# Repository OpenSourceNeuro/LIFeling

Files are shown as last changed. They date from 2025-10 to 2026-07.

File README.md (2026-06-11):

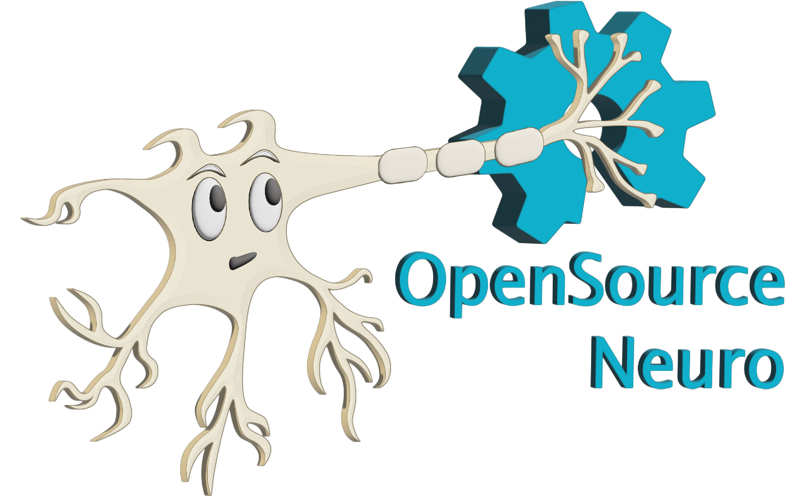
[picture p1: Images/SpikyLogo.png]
<p align="left">

<h1 align="center"> LIFeling </h1></p>
<h3 align="center">  An analog LIF/AdEx “silicon neuron” for teaching & exploration</h3></p>
<p align="center"><h6 align="right">developed by M.J.Y. Zimmermann, A. Koumoundourou</h6></p>

<br></br>

## What is LIFeling
<div>
<p style='text-align: justify;'>
LIFeling is a low-cost, through-hole–friendly analog circuit that emulates a spiking neuron in real time. It implements the Leaky Integrate-and-Fire (LIF) and Adaptive Exponential Integrate-and-Fire (AdEx) dynamics using op-amps, RC networks, comparators, and simple transistor/MOSFET logic.

<p style='text-align: justify;'>
Students can turn knobs (capacitance, leak, synaptic gains, adaptation, threshold, reset) and immediately see how membrane voltage and spikes change—just like a patch-clamp demo, but on an interactive PCB.
</p>

<p style='text-align: justify;'>
LIFeling lives alongside our digital <a href="https://github.com/OpenSourceNeuro/Spikeling">Spikeling</a>: project; where Spikeling runs code, LIFeling is purely analog, making the math–to–hardware mapping very explicit. (For background on AdEx/LIF and neuromorphic “silicon neurons”, <a href="https://www-sop.inria.fr/members/Mathieu.Desroches/teaching/MTSN/Articles/Brette_Gertsner_JNeurophysiol_2005.pdf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">See the references</a>).
</p>

<p style='text-align: justify;'>
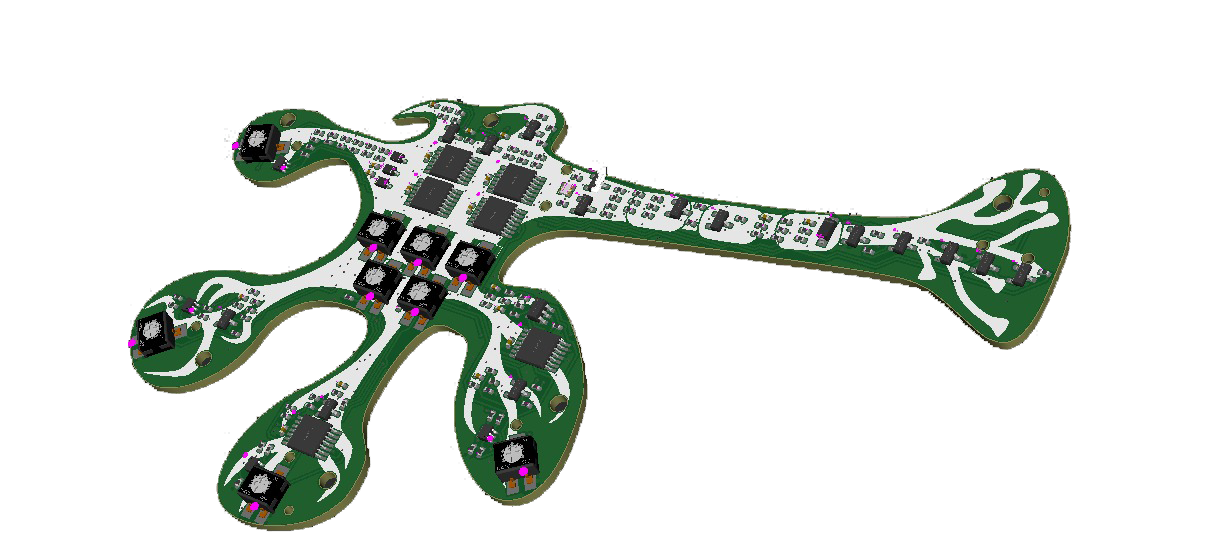
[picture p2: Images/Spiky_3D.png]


This project is licensed under the [GNU General Public License v3.0](https://github.com/OpenSourceNeuro/Spikeling-V2/blob/main/LICENSE)<br>
The hardware is licensed under the [CERN OHL v1.2](https://github.com/OpenSourceNeuro/Spikeling-V2/blob/main/PCB%20-%202.2c/LICENSE)
</p>
</div>

<br>

***

## Objectives
- **Pedagogy** first: Make classical neuron equations tangible with knobs, LEDs, and BNC/TTL I/O so learners can fit parameters from data and build intuition.

- **Open, repairable, reproducible**: THT-preferred BOM where possible; common op-amps (e.g., MCP6004), LM339-class comparators, simple passives; documented test procedures.

- **Immediate feedback**: Real-time dynamics without sampling/latency; scope-friendly nodes for Vm, synaptic currents, threshold comparator, adaptation current.

- **Bridging models**: Start with LIF; switch in AdEx features (exp spike term + adaptation) to show how richer behaviours emerge with just a few components.

- **Teaching exercises**: Provide ready-to-run lab activities (τm measurement, I–F curves, refractory period, synaptic summation, adaptation fitting, noise & reliability). (See Exercises below.)

- **Interoperability**: Optional headers/IO for stimulus/recording from microcontrollers (ESP32/Arduino) and classroom oscilloscopes.

## The models LIFeling implements

#### 1) Leaky Integrate-and-Fire (LIF)

```math
C_m * dV/dt = -g_L * (V - E_L) + I_syn(t) + I_inj(t) - w(t)
```

If V >= V_th  ⇒  V ← V_reset  and hold for τ_ref

with synaptic drive typically modeled as:

```math
I_syn(t) = Σ_i g_i(t) * (E_i - V)
```

LIF captures integration, leakage, threshold, reset, and refractory with minimal parameters.

### Adaptive Exponential Integrate-and-Fire (AdEx)

```math
C_m * dV/dt = -g_L * (V - E_L)
              + g_L * Δ_T * exp((V - V_T)/Δ_T)
              - w
              + I_syn(t) + I_inj(t)

τ_w * dw/dt = a * (V - E_L) - w

If V >= V_spike  ⇒  V ← V_reset  and  w ← w + b
```

AdEx adds a soft, exponential spike-initiation term and an adaptation state w, reproducing rich firing patterns with few parameters.

- Further reading: Brette & Gerstner 2005 (AdEx); Dayan & Abbott 2001 (LIF fundamentals); Indiveri et al. 2011 (neuromorphic neuron circuits).

## Circuit ↔ equation map

| Equation term | Biological meaning | Circuit element(s) | What to adjust / observe |
|---|---|---|---|
| `C_m` | Membrane capacitance (area/biophysics) | Selectable capacitor bank; front-panel selector | Larger `C_m` → slower `V_m` dynamics; measure a step response to estimate `τ_m = C_m / g_L`. |
| `g_L`, `E_L` | Leak conductance & resting potential | Potentiometer or resistor ladder to ground/bias; optional reference sets `E_L` | Increasing `g_L` lowers input resistance and shortens `τ_m`; trimming `E_L` shifts the baseline. |
| `I_syn = Σ g_i(t) · (E_i − V)` | Synaptic drive (EPSC/IPSC) with reversal | 4× synapse shapers (RC) with gain/polarity pots; bias selects excitatory vs inhibitory | Temporal summation, shunting inhibition; switch time constants (fast/slow) to compare PSP shapes. |
| `Δ_T`, `V_T` | Spike-onset sharpness & soft threshold (AdEx) | Exponential I–V subcircuit (diode/transconductance shaping) feeding the membrane node | Increase `Δ_T` for smoother onset; adjust `V_T` to shift effective threshold and excitability. |
| `w`, `a`, `b`, `τ_w` | Adaptation current and kinetics | Slow RC + transconductance; spike-triggered charge increment into `w` | Fit `a`, `b`, `τ_w` from step protocols; observe spike-frequency adaptation and after-spike effects. |
| Spike detect & reset | Action potential event and absolute refractory | LM339-class comparator → MOSFET/analog switch clamp to `V_reset`; monostable sets `τ_ref` | Tune `V_th`, `V_reset`, `τ_ref`; verify with ISI histograms and two-pulse tests. |
| `I_inj` | Current clamp / external stimulus | BNC/3.5 mm input, on-board button, or photodiode path | Use steps/ramps/noise to probe `f–I` curves, threshold, reliability, and dynamic range. |

## Biological correspondence: what’s faithful vs abstracted

Faithful: passive membrane (R–C), synaptic time courses (first-order), EPSP/IPSP summation, threshold/reset phenomenology, refractory period, spike-frequency adaptation.

Abstracted: no detailed action-potential waveform (we model its effect via threshold/reset); ion-channel kinetics are lumped into **g_L**, the exponential term, and **w** rather than Hodgkin–Huxley-style gates.

Optional background: when teaching resting potentials and synaptic reversal, connect channel-specific reversal potentials **E_i** to Nernst/GHK equations (see References).

## Front-panel controls (typical)

**Membrane**: C_m selector, Leak pot (g_L), E_L trim.

**Synapses (×4)**: Gain pot, Polarity switch (E/I), τ_s switch (fast/slow).

**AdEx**: V_T, Δ_T trims (soft threshold), Adaptation (a, b, τ_w) pots.

**Spiking**: V_th, V_reset, τ_ref trims; Spike LED.

**I/O**: Vm out (scope), Spike out (TTL), Stim in (BNC/3.5 mm), light-sensor jack.

Start with τ_m ≈ 5–100 ms and spike thresholds ~0.8–1.8 V relative to your virtual ground (adjust for your supply).

## Quick start (bench)

Power & baseline. Power the board; set all gains mid-range; choose C_m, set leak mid.

Wire the scope. CH1 = Vm; CH2 = Spike TTL.

Elicit spikes. Inject a 0.5–2 s current step; adjust threshold/reset until regular spiking appears.

Add small Δ_T and adaptation (τ_w ≈ 200–500 ms). Watch firing adapt down.

Play with synapses. Use fast EPSPs and slower IPSPs to demonstrate temporal summation and shunting inhibition.

## Suggested classroom exercises

**Measure membrane time constant τ_m.**
Inject a small subthreshold step; fit V(t) = E_L + ΔV*(1 - exp(-t/τ_m)). Recover C_m or g_L and compare to knob settings.

**I–F (f–I) curve & rheobase.**
Ramp I_inj and record firing rate. Fit slope and rheobase; show how g_L and C_m change slope/offset.

**Refractory period.**
Deliver two pulses separated by Δt; find minimum Δt producing two spikes; compare to τ_ref.

**Synaptic summation and shunting.**
Pair an EPSP with a near-coincident IPSP; demonstrate divisive gain control by increasing inhibitory conductance (shunting).

**Spike-frequency adaptation (AdEx).**
Step-current protocol; fit a, b, τ_w from the early/late rates and the post-spike adaptation jump.

**Soft vs hard threshold.**
Compare LIF (hard V_th) to AdEx (Δ_T > 0). Show smoother onset and different ISI variability with AdEx.

**Noise & reliability.**
Add small noise to I_inj; plot spike-time jitter vs g_L. Discuss reliability/variability trade-offs.

**Analog vs digital (optional).**
Recreate one exercise on a microcontroller neuron (e.g., Izhikevich) and compare dynamics, latency, and parameter identifiability.

## Acknowledgments

Foundation: This project is based on Lu.i — https://github.com/giant-axon/lu.i-neuron-pcb

Thanks to the neuromorphic-hardware community for decades of open designs and teaching inspiration.

## References & further reading

AdEx model — Brette, R. & Gerstner, W. (2005). Adaptive Exponential Integrate-and-Fire Model as an Effective Description of Neuronal Activity. Journal of Neurophysiology, 94(5), 3637–3642. https://doi.org/10.1152/jn.00686.2005

LIF & synapses — Dayan, P. & Abbott, L. F. (2001). Theoretical Neuroscience. MIT Press. (See chapters on LIF, synapses, and I–F curves.)

Neuromorphic circuits — Indiveri, G., Linares-Barranco, B., et al. (2011). Neuromorphic Silicon Neuron Circuits. Frontiers in Neuroscience, 5:73. https://doi.org/10.3389/fnins.2011.00073
 (Open access)

Spiking for teaching (digital reference) — Baden, T., James, B., et al. (2018). Spikeling: a low-cost hardware implementation of a spiking neuron for neuroscience teaching and outreach. PLOS Biology. https://doi.org/10.1371/journal.pbio.2006760

Ion channels & reversals (background) — Hille, B. (2001). Ion Channels of Excitable Membranes (3rd ed.). Sinauer. (Nernst/GHK chapters)

## Contributing

Issues and PRs welcome!
When reporting results, please include:

Scope captures (Vm & Spike TTL),

Knob settings (Cm, gL, ΔT, Vth, Vreset, τref, a, b, τw),

The stimulus used (step amplitude, duration, ramp slope, synaptic timing),

Supply voltage and any modifications to the reference design.

## FAQ

Is this a “real” action potential?
No—the analog spike is implicit (threshold/reset). That’s by design and matches reduced-model pedagogy.

Why analog instead of a microcontroller?
Zero-latency dynamics and a literal circuit-to-equation mapping you can probe with a scope—excellent for intuition building.

Can I add more biology?
Yes: add synapse types (different τ_s), noise sources, or a second compartment. Use the AdEx literature and neuromorphic reviews as guidance.

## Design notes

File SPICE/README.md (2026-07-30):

# LIFeling physical-netlist SPICE validation system

This reconstruction replaces the earlier block-level behavioural generator with a physical-pin-driven workflow for the attached KiCad export dated **2026-07-29 20:56:15**.

## Core rule

`sources/LIFeling.net` is authoritative for references, values, physical pins and nets. The schematic is retained as a visual cross-check. No intended equation or historical mapping is allowed to create electrical connectivity independently of the export.

## What the system produces

- `reports/source_manifest.json` and `.csv`: source sizes, SHA-256 hashes, export metadata, repository comparison commit and execution environment.
- `reports/source_lock.json`: stable source-only fingerprint payload used for reproducible deck names; volatile timestamps and host paths are excluded.
- `reports/netlist_inventory.csv`: one row per physical component pin, with manufacturer, part, net, functional block and model mapping.
- `reports/component_model_coverage.csv`: one row per reference; no silent omissions are permitted.
- `reports/model_manifest.json` and `.csv`: exact part/manufacturer, source/package, model revision/date, actual installed declaration, wrapper requirement, compatibility gate, checksum, licence status and limitations.
- `reports/connectivity_audit.md`: package-pin and functional-topology audit.
- `reports/schematic_crosscheck.md`: every exported reference and footprint checked against placed schematic symbols.
- `generated/*.cir`: reproducible ngspice decks with source hashes embedded in comments.
- `generated/*.csv`, diagnostics and logs after execution.
- `reports/validation_report.md`: reader-facing result and limitation report.
- `OFFICIAL_MODEL_SOURCES.md`: official-package register and activation policy.
- `REPOSITORY_MIGRATION.md`: replacement/integration instructions for the GitHub repository.
- `THIRD_PARTY_MODELS.md`: licence and manufacturer-mismatch notes.

## Profiles

- `hybrid` (default): supplied official Microchip MCP6001/2/4 macro-model plus explicit portable models for uninstalled/unapproved device packages.
- `portable`: same deterministic topology with only locally inspectable model sources.
- `vendor`: strict gate. It refuses to run until every required official package is installed, its actual declaration is inspected, an adapter terminal order is approved, and `models/vendor/vendor_adapters.lib` exposes all stable wrapper interfaces. The vendor deck includes that adapter library instead of the portable library; it never guesses a model terminal order.

## Commands

From this folder. `Spice.py` reruns the packaged static reconstruction tests automatically unless `--skip-static-tests` is supplied:

```powershell
python -m unittest discover -s tests -v
python Spice.py generate --suite
python Spice.py run --suite --ngspice-binary auto
```

On Windows, the complete runner is:

```powershell
.\run_full_validation.ps1 -Profile hybrid -NgspiceBinary "C:\Spice64\bin\ngspice.exe"
```

Generate without simulation:

```powershell
.\run_full_validation.ps1 -GenerateOnly
```

Inspect/download current official model packages from the URLs locked in `model_registry.json`:

```powershell
python Spice.py fetch-models
```

Downloaded TI packages are placed under `models/downloads/` and extracted under `models/vendor/`. The downloader records checksums and every actual `.SUBCKT` declaration, but does not approve or use a newly discovered terminal order automatically.

## Important authoritative findings

- Corrected TLV7044 PW-14 physical pins are present on U4, U5 and U6.
- RV4 physically selects 470 nF, 1 µF, 2.2 µF, 4.7 µF and 10 µF through U9–U13.
- `Peak_Window` is active-high and controls U14 and U20.
- U23 is physically wired as the TLV9041 stimulus amplifier; its transfer emerges from U23 and R92–R96.
- The attached export uses **R96**, not R97, as the 100 kΩ `V_Stim_Drive` to `Vm_Int` resistor. R97 is absent.
- U6B has INB+ at VDD, INB− at GNDREF and an unconnected output.
- `TPS610995DRVR` is the fixed **3.6 V** variant; the old 3.3 V boost assumption is not retained.
- U21 matches the official REF3020 DBZ physical order: pin 1 IN, pin 2 OUT, pin 3 GND; vendor macro-model terminal order remains separately gated.

## Validation boundary

Passing simulations show that a documented SPICE representation behaves as specified under the model assumptions. They do not prove hardware operation, ESD survival, sustained classroom-fault tolerance, battery life, PCB parasitics, EMC, production yield or safety. Bench correlation requirements are listed in `reports/validation_report.md`.

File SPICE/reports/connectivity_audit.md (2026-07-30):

# LIFeling connectivity and pin-map audit

Netlist: `LIFeling.net`
Export: `2026-07-29T20:56:15` using `Eeschema 10.0.1`

| Check | Severity | Result | Evidence |
|---|---|---|---|
| `pinmap.U4.tlv7044` | error | **PASS** | All 14 physical pin functions match. |
| `pinmap.U5.tlv7044` | error | **PASS** | All 14 physical pin functions match. |
| `pinmap.U6.tlv7044` | error | **PASS** | All 14 physical pin functions match. |
| `pinmap.family.mcp6004` | error | **PASS** | All physical pin functions match. |
| `pinmap.family.tlv9001` | error | **PASS** | All physical pin functions match. |
| `pinmap.family.tlv9041` | error | **PASS** | All physical pin functions match. |
| `pinmap.family.tlv7031` | error | **PASS** | All physical pin functions match. |
| `pinmap.family.ts5a3166` | error | **PASS** | All physical pin functions match. |
| `pinmap.family.tps610995` | error | **PASS** | All physical pin functions match. |
| `topology.rv4.comparators` | error | **PASS** | Physical comparator channels match the one-hot window equations. |
| `topology.rv4.capacitors` | error | **PASS** | Monotonic physical switch/capacitor chain confirmed. |
| `topology.peak_window.active_high` | error | **PASS** | U6A pins: OUT=Peak_Window, IN+=Spike_Pulse, IN-=V_Threshold; R51=['Peak_Window', 'VDD']; U14/U20 controls=[('U14', '4'), ('U20', '4')]. |
| `topology.stimulus.u23` | error | **PASS** | Electrical topology matches the intended transfer; the output-to-Vm resistor is physically R96, not R97. |
| `naming.stimulus.r96_r97` | warning | **WARNING** | R97 is absent. R96 is 100 kΩ between V_Stim_Drive and Vm_Int; there is no VDD pull-up on V_Stim_Drive. |
| `topology.u6b.unused` | error | **PASS** | INB+=VDD, INB-=GNDREF, OUTB=unconnected-(U6B-OUTB-Pad7) |
| `power.boost.tps610995_fixed_output` | warning | **WARNING** | Netlist U7 value=TPS610995DRVR. Portable switching model VSET is locked to 3.6 V; previous 3.3 V behavioural assumptions are rejected. |
| `pinmap.u21.ref3020_physical` | error | **PASS** | KiCad mapping: pin1=VDD, pin2=VREF_2V048, pin3=GNDREF. |
| `model.u21.ref3020_vendor_terminal_order` | warning | **WARNING** | The physical package order is verified, but the downloaded model's actual .SUBCKT terminal order must still be inspected and wrapped before vendor instantiation. |

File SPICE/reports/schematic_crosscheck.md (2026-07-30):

# KiCad schematic / exported-netlist cross-check

Placed schematic symbols: **416**; exported netlist components: **216**.

Blocking cross-check failures: **0**; metadata warnings: **0**.

Every exported reference is present as a placed schematic symbol and all exported footprints match the placed-symbol footprints after library-prefix normalization.

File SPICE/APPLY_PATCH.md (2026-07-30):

# LIFeling SPICE cold-start separation patch v9

Run `python -B .\apply_v9.py` from the `SPICE` directory.

This patch changes the full-board N06 cold-start simulation from the dynamic-SOC
CR2032 subcircuit to a fixed-SOC Thevenin equivalent:

- OCV at SOC 0.75: 2.92125 V
- series resistance: 35 ohm
- source ramp: 0 to 2.92125 V over 1 ms
- simulation horizon: remains 50 ms

The dynamic battery library model is retained. It should be validated in a
separate battery-only deck, rather than inside the complete 1 MHz switching
board, because the two models operate on radically different timescales.

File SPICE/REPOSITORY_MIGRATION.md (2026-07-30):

# Repository migration guide

This folder is a replacement for the current `SPICE/` validation implementation, not a patch to the older behavioural generator.

## Recommended integration

1. Create a branch from the repository commit recorded in `reports/repository_snapshot.json`.
2. Preserve the current `SPICE/` directory as an archive or compare-only tag.
3. Copy this rebuild into `SPICE/`.
4. Keep `sources/LIFeling.net` synchronized with `PCBs/LIFeling/LIFeling.net`, or invoke `Spice.py` with `--netlist` pointing directly to the current export.
5. Run `run_full_validation.ps1 -GenerateOnly` first. Review `reports/connectivity_audit.md`, `reports/component_model_coverage.csv`, and `reports/model_manifest.csv`.
6. Install ngspice and run the complete suite without `-GenerateOnly`.
7. Do not select the strict `vendor` profile until downloaded model declarations and wrappers are reviewed and smoke-tested.
8. Commit generated reports only if repository policy intentionally tracks simulation artifacts. Generated transient CSV/PNG data can be large.

## Deliberate breaking changes

- The old stage/backend compatibility flags are removed.
- Electrical connectivity is never recreated from historical block equations.
- Missing active model rules and silent component omissions are fatal.
- Vendor models are never activated from a package filename alone.
- `TPS610995DRVR` is treated as the 3.6 V fixed-output part.
- The latest netlist's output-injection resistor is `R96`; no fictitious `R97` is created.

## Suggested repository layout

```text
SPICE/
├─ Spice.py
├─ run_full_validation.ps1
├─ lifeling_spice/
├─ models/
│  ├─ portable/
│  ├─ provided/
│  ├─ downloads/       # normally ignored
│  └─ vendor/          # normally ignored unless redistribution is permitted
├─ sources/
├─ tests/
├─ generated/          # generated decks and simulation outputs
└─ reports/
```

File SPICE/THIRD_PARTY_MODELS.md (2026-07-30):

# Third-party model and redistribution notes

- `models/provided/MCP6001.txt` contains Microchip's model licence. Its use is restricted by the terms embedded in that file.
- `models/provided/MMBT3904.spice.txt` is a Diodes Incorporated model, while the current netlist metadata identifies a different manufacturer. It is retained for comparison and is not silently treated as an exact-vendor match.
- `models/provided/1n4148_spice.lib` is an inspectable model whose manufacturer does not clearly match the current ordered-part metadata. The hybrid deck uses its documented portable model card rather than claiming an exact match.
- `models/provided/lm2901.lib` is legacy comparison material and is not used for the current TLV7044 circuit.
- TI packages downloaded by `Spice.py fetch-models` are placed outside the provided-model directory. Their redistribution must be reviewed before committing or sharing them.

The generated reports record selected model paths and SHA-256 checksums so a future model replacement is reviewable.

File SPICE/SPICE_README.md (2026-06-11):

# LIFeling SPICE simulation

This folder contains the Python/ngspice simulation workflow for the Vm-relevant part of the **LIFeling** analog neuron circuit.

The main simulation file is:

```text
Spice.py
```

`Spice.py` generates a SPICE deck, runs a transient simulation, saves compact trace data, creates plots, and writes a text report with validation diagnostics.

The model is a **controlled behavioural SPICE model**. It is not a raw KiCad-exported netlist. Its purpose is to make the important LIFeling circuit blocks easy to simulate, inspect, and validate while keeping the generated SPICE deck readable.

---

## 1. What this simulation is for

The simulation is intended to answer practical circuit questions such as:

- Does the membrane voltage integrate and leak as expected?
- Does the threshold comparator trigger at the intended point?
- Does the AP / spike pulse path fire correctly?
- Does the peak/reset sequence recover, or does it latch?
- Does the external live output `Vm_Ext` show a usable neuron-like trace?
- Does the adaptation path affect firing over time?
- Do synaptic inputs perturb the membrane in the expected direction?
- Does the buffered `V_Leak_Ref_Max` reference remain stable when RV1 and RV6-RV9 are connected?
- How do RV1, RV2, RV3, RV4, RV5, RV6, RV7, RV8, and RV9 affect behaviour?

The most important user-facing trace is:

```text
Vm_Ext
```

`Vm_Ext` is the modelled physical/live analog output. `Vm_Int` is still saved because it is the internal membrane computation node, but it is not the final output that a user would normally probe.

---

## 2. Model fidelity and limitations

This model is best used for **functional validation**, debugging, and design exploration. It is not intended to replace final analogue verification against the PCB, oscilloscope captures, and component-level measurements.

Important simplifications:

| Area | How it is represented |
|---|---|
| Op-amps | Default mode uses robust behavioural/follower approximations. Vendor models are optional. |
| Comparators | Default mode uses an open-drain behavioural comparator approximation. |
| TS5A3166 switches | Represented by idealised switch models with finite on-resistance. |
| Coin-cell supply | Optional simplified `VBAT_RAW -> RBAT -> VDD` model with local decoupling. |
| RV4 capacitor selection | Represented as an idealised membrane-capacitor selector. |
| RGB LEDs and visual indicators | Omitted to keep the Vm model focused. |
| Boost converter / full power front end | Not modelled in detail. |
| PCB parasitics | Not modelled except for selected explicit capacitors/resistors. |

The default fallback models are intentionally stable and readable. Use `--strict-vendor` only when the required vendor model files are present and their pin order has been checked.

---

## 3. Circuit blocks currently modelled

| Circuit block | Modelled purpose |
|---|---|
| Supply rail | Ideal `VDD` or simplified coin-cell model `VBAT_RAW -> RBAT -> VDD`, with local decoupling. |
| `V_Leak_Ref_Max` reference | R4/R5 raw divider followed by U2A buffer. The buffered node feeds downstream reference uses. |
| RV1 / leak reference | Sets `/V_Leak_ref`, then U1A buffers it to `V_Leak`. |
| Passive membrane | RV2 leak path, selected membrane capacitor, `Vm_Int`, and clamp approximations. |
| External stimulus path | `Stimulus_Ext` through the U19B closed-loop equivalent into `Vm_Int`. |
| Threshold detection | U6B comparator, AP generation, `/Rising_AP`, `Spike_Pulse`, and negative clamp. |
| Peak injection | R8/R9 peak reference, U2C buffer, R49/U14 peak switch into `Vm_Int`. |
| Reset window | U6A/U6C timing, peak/reset windows, reset-current injection chain. |
| Spike output | U6D/R81/R82/D18 approximation for `Spike_Out`. |
| Adaptation | U1B/U1C/U1D, `/Vkick`, `Vw`, and Q2 adaptation current sink. |
| Synaptic inputs | Syn1-Syn4 input clamps, switches, set voltages, RV5 decay, and `V_Syn_State`. |
| Live Vm output | `Vm_Int -> R90/C38 Vm_Display_In`, optional display-spike charge through U20/R91, then U8/R1/C14 to `Vm_Ext`. |
| Component tolerances | Optional deterministic random resistor/capacitor/pot variation. |

---

## 4. Current reference and Vm output paths

### 4.1 Buffered leak reference

The current model represents the updated hardware reference path:

```text
R4/R5 -> V_Leak_Ref_Max_Raw -> U2A buffer -> V_Leak_Ref_Max
```

The buffered `V_Leak_Ref_Max` node is then used as the high-side reference for RV1 and, when synaptic circuitry is enabled, for RV6-RV9.

This matters because RV6-RV9 should not load the raw R4/R5 divider directly during synaptic tests.

### 4.2 Internal membrane vs live output

The model distinguishes between two membrane-related traces:

| Trace | Meaning |
|---|---|
| `Vm_Int` | Internal membrane computation node. |
| `Vm_Ext` | External/live analog output after display-spike synthesis and the U8 output path. |

The live-output path is:

```text
Vm_Int
  -> R90/C38 -> Vm_Display_In
  -> U8/R1/C14 -> Vm_Ext
```

In `threshold_reset` and `threshold_reset_adapt` stages, a short display-spike charge is also injected into `Vm_Display_In` through:

```text
V_Peak_Drive -> R91 -> U20 -> Vm_Display_In
```

This means `Vm_Ext` can show a more visible spike-like output while `Vm_Int` remains the internal LIF computation node.

---

## 5. Folder layout

Expected folder structure:

```text
SPICE/
├─ Spice.py
├─ README.md
├─ run_full_validation.ps1
├─ models/
│  ├─ MCP6001.txt
│  ├─ MMBT3904.spice.txt
│  ├─ 1n4148_spice.lib
│  ├─ TLV7044.lib              optional / required only for --strict-vendor
│  ├─ BSS138.lib               optional / required only for --strict-vendor
│  └─ RB521S30.lib             optional / required only for --strict-vendor
├─ LIFeling_pyspice_output/    generated simulation decks, logs, CSV files, reports, and PNG plots
└─ LIFeling_validation_logs/   validation-suite console summaries, when committed
```

`LIFeling_pyspice_output/` is created automatically when `Spice.py` runs. It contains generated SPICE decks, CSV traces, PNG plots, ngspice logs, and text reports.

`run_full_validation.ps1` is the current validation-suite entry point. It runs a practical battery of syntax, threshold/reset, Vm output, cold-start, synapse, stimulus, and RV behaviour checks. Some comments or default path names inside older versions of that script may still contain legacy Spiky wording; the README uses the current LIFeling project naming.

---

## 6. Requirements

### 6.1 Required for normal use

You need:

1. Python 3.
2. The Python packages used by the script:

```powershell
pip install numpy pandas matplotlib
```

3. ngspice installed and available either on the system `PATH` or through an explicit path.

The recommended backend is:

```text
--backend ngspice-cli
```

### 6.2 Optional PySpice backend

`Spice.py` also contains a PySpice backend:

```text
--backend pyspice
```

This is optional. For most Windows/PyCharm workflows, the command-line ngspice backend is simpler and more robust.

### 6.3 Optional vendor models

Normal runs use internal fallback models. Vendor model files are only required when using:

```text
--strict-vendor
```

Before using strict-vendor mode, confirm that all expected model files exist in `SPICE/models/` and that the wrapper pin orders match the vendor `.SUBCKT` definitions.

---

## 7. ngspice path setup

The script can search automatically:

```powershell
--ngspice-binary auto
```

You can also pass the full path explicitly. On Windows, prefer quoting the path and using either escaped backslashes or forward slashes:

```powershell
--ngspice-binary "C:/Users/mzimm/Documents/Spice64/bin/ngspice.exe"
```

or:

```powershell
--ngspice-binary "C:\Users\mzimm\Documents\Spice64\bin\ngspice.exe"
```

You can also define an environment variable named `NGSPICE_BINARY` pointing to `ngspice.exe`.

---

## 8. Quick start

Open a terminal in the `SPICE` folder.

Check that you are in the correct folder:

```powershell
dir
```

You should see at least:

```text
Spice.py
README.md
```

### 8.1 Syntax check

This only checks that Python can parse the script:

```powershell
.\.venv\Scripts\python.exe -m py_compile .\Spice.py
```

No output means the syntax check passed.

### 8.2 Recommended first simulation

Run a complete LIF path without synaptic inputs:

```powershell
.\.venv\Scripts\python.exe .\Spice.py --stage threshold_reset_adapt --backend ngspice-cli --ngspice-binary auto --trace-set core --supply-mode coin --vbat 3 --rbat 50 --startup-mode operating --ignore-start-ms 20 --rv1 0.7 --rv2 0.5 --rv3 0.8 --cmem-mode rv4 --rv4 0.3 --tstop 1.5 --tstep 1u --maxstep 1u
```

This is the recommended first check because it includes the passive membrane, threshold, reset, peak injection, adaptation, supply model, and live output.

### 8.3 Same run with debug traces

Use debug traces when something looks wrong:

```powershell
.\.venv\Scripts\python.exe .\Spice.py --stage threshold_reset_adapt --backend ngspice-cli --ngspice-binary auto --trace-set debug --supply-mode coin --vbat 3 --rbat 50 --startup-mode operating --ignore-start-ms 20 --rv1 0.7 --rv2 0.5 --rv3 0.8 --cmem-mode rv4 --rv4 0.3 --tstop 500m --tstep 1u --maxstep 1u
```

### 8.4 Full LIF with all synaptic inputs enabled

```powershell
.\.venv\Scripts\python.exe .\Spice.py --stage threshold_reset_adapt --backend ngspice-cli --ngspice-binary auto --trace-set core --supply-mode coin --vbat 3 --rbat 50 --startup-mode operating --ignore-start-ms 20 --rv1 0.7 --rv2 0.5 --rv3 0.8 --cmem-mode rv4 --rv4 0.3 --syn-all-enable --rv5 0.5 --rv6 0.5 --rv7 0.5 --rv8 0.5 --rv9 0.5 --syn1-delay 150m --syn2-delay 180m --syn3-delay 210m --syn4-delay 240m --syn1-width 5m --syn2-width 5m --syn3-width 5m --syn4-width 5m --tstop 1.5 --tstep 1u --maxstep 1u
```

### 8.5 Stimulus path check

```powershell
.\.venv\Scripts\python.exe .\Spice.py --stage threshold_reset_adapt --backend ngspice-cli --ngspice-binary auto --trace-set debug --supply-mode coin --vbat 3 --rbat 50 --startup-mode operating --ignore-start-ms 20 --rv1 0.7 --rv2 0.5 --rv3 0.8 --cmem-mode rv4 --rv4 0.3 --stim-dc 0.2 --tstop 500m --tstep 1u --maxstep 1u
```

### 8.6 Cold-start stress test

```powershell
.\.venv\Scripts\python.exe .\Spice.py --stage threshold_reset_adapt --backend ngspice-cli --ngspice-binary auto --trace-set core --supply-mode coin --vbat 3 --rbat 50 --startup-mode cold --ignore-start-ms 20 --rv1 0.7 --rv2 0.5 --rv3 0.8 --cmem-mode rv4 --rv4 0.3 --tstop 1.5 --tstep 1u --maxstep 1u
```

---

## 9. Simulation stages

The `--stage` option controls how much of the circuit is included.

| Stage | Included blocks | Main use |
|---|---|---|
| `passive` | Supply/reference path, leak, membrane capacitor, `Vm_Int`, `Vm_Ext` output path without reset/peak switching. | Passive leak and charging checks. |
| `threshold` | Passive stage plus threshold comparator and AP/spike-pulse generation. | Threshold logic checks. |
| `threshold_reset` | Threshold stage plus peak injection, reset window, reset current, and `Spike_Out`. | Spike/reset behaviour without adaptation. |
| `threshold_reset_adapt` | Full model: reset, adaptation, optional stimulus, optional synapses. | Main operating mode. |

Most project checks should use:

```text
--stage threshold_reset_adapt
```

---

## 10. Trace sets

### 10.1 Core trace set

Use:

```text
--trace-set core
```

for normal runs. Core traces are intended to keep CSV files and plots readable.

Typical core traces include:

```text
Vm_Ext
Vm_Int
V_Leak
VDD              when using coin supply
V_Threshold
AP
Spike_Pulse
Spike_Out
Peak_Window
Reset_Window
Vw
Vw_buff
```

When synapses are enabled, core traces also include:

```text
V_Syn_State
Syn1_Spike / V_Syn1_Set
Syn2_Spike / V_Syn2_Set
Syn3_Spike / V_Syn3_Set
Syn4_Spike / V_Syn4_Set
```

### 10.2 Debug trace set

Use:

```text
--trace-set debug
```

when you need internal reference and control nodes.

Debug traces can include:

```text
V_Leak_Ref_Max_Raw
V_Leak_Ref_Max
V_Peak_Ref
V_Peak_Drive
Peak injection switch node
Reset timer/reference nodes
Reset injection enable/gate nodes
U1B adaptation output
Stimulus amplifier internal nodes
V_Syn_Drive
RV5 decay node
```

---

## 11. Main command-line options

### 11.1 Power options

| Option | Meaning |
|---|---|
| `--supply-mode ideal` | Perfect voltage source on `VDD`. Best for isolating circuit logic from supply sag. |
| `--supply-mode coin` | Battery model: `VBAT_RAW -> RBAT -> VDD`. Best for realistic stress checks. |
| `--vdd 3` | Ideal supply voltage when using `--supply-mode ideal`. |
| `--vbat 3` | Battery open-circuit/source voltage when using `--supply-mode coin`. |
| `--rbat 50` | Battery/internal resistance in ohms when using `--supply-mode coin`. |
| `--cdec-local` | Local bypass capacitance. |
| `--cdec-bulk` | Board-level bulk capacitance. |
| `--cdec-reservoir` | Larger reservoir capacitance. |
| `--cdec-esr` | ESR applied to decoupling capacitors. |

### 11.2 Startup options

| Option | Meaning |
|---|---|
| `--startup-mode operating` | Starts VDD capacitors and reset timer precharged. Best for normal behaviour. |
| `--startup-mode cold` | Starts VDD capacitors, reset timer, and Vm from cold initial conditions. Best for power-on tests. |
| `--ignore-start-ms 20` | Ignores the first 20 ms for event counts and VDD sag diagnostics. |
| `--cold-vm-initial 0` | Vm initial condition used only in cold-start mode. |

### 11.3 Potentiometers

All RV values are fractions from 0 to 1.

| Option | Circuit meaning |
|---|---|
| `--rv1` | Leak reference set point. |
| `--rv2` | Leak conductance / membrane leak rate. |
| `--rv3` | Adaptation strength/decay path control. |
| `--rv4` | Idealised membrane capacitance selector when `--cmem-mode rv4` is used. |
| `--rv5` | Synaptic-state decay back toward `V_Leak`. |
| `--rv6` | Synapse 1 set voltage. |
| `--rv7` | Synapse 2 set voltage. |
| `--rv8` | Synapse 3 set voltage. |
| `--rv9` | Synapse 4 set voltage. |

Examples:

```text
--rv1 0.7
--rv2 0.5
--rv4 0.3
--rv9 1.0
```

### 11.4 Membrane capacitance options

Use RV4-style selection:

```text
--cmem-mode rv4 --rv4 0.3
```

or manually force a capacitance:

```text
--cmem-mode manual --cmem 2.2u
```

Supported SPICE suffix examples:

```text
470n
1u
2.2u
4.7u
10u
```

### 11.5 Time options

| Option | Meaning |
|---|---|
| `--tstop 1.5` | Simulate for 1.5 seconds. |
| `--tstep 1u` | Requested output time step. |
| `--maxstep 1u` | Maximum internal ngspice step. Smaller values are slower but more precise. |

SPICE suffixes:

```text
m = milli = 1e-3
u = micro = 1e-6
n = nano  = 1e-9
```

Examples:

```text
150m = 150 ms
1u   = 1 microsecond
```

### 11.6 Synaptic options

| Option | Meaning |
|---|---|
| `--syn1-enable` | Enable synapse 1. |
| `--syn2-enable` | Enable synapse 2. |
| `--syn3-enable` | Enable synapse 3. |
| `--syn4-enable` | Enable synapse 4. |
| `--syn-all-enable` | Enable all four synapses. |
| `--syn-amp` | Synaptic input pulse high voltage. |
| `--syn1-delay`, `--syn1-width`, `--syn1-period` | Synapse 1 pulse timing. Equivalent options exist for synapses 2-4. |
| `--syn-ref-mode schematic` | Current schematic behaviour: RV6-RV9 use buffered `V_Leak_Ref_Max`. |
| `--syn-ref-mode legacy_direct` | Comparison mode: RV6-RV9 use raw `V_Leak_Ref_Max_Raw`. |

For normal use, keep:

```text
--syn-ref-mode schematic
```

`buffered` is accepted as a deprecated alias of the schematic behaviour.

### 11.7 Tolerance options

The model can apply deterministic random tolerances:

```powershell
--tol-mode random --tol-seed 1 --res-tol-pct 1 --cap-tol-pct 10 --pot-tol-pct 5
```

Tolerance mode is useful for sensitivity checks. Because the randomisation is deterministic for a given seed, runs can be repeated exactly.

---

## 12. Generated files

Each normal run writes files into:

```text
LIFeling_pyspice_output/
```

Typical files:

| File pattern | Meaning |
|---|---|
| `LIFeling_vm_<suffix>.cir` | Generated SPICE deck. Useful for checking the exact ngspice input. |
| `LIFeling_vm_<suffix>.csv` | Compact saved traces used for plotting and later analysis. |
| `LIFeling_vm_<suffix>.png` | Multi-trace plot of all saved traces. |
| `LIFeling_vm_<suffix>_vmint_vmext.png` | Clean comparison plot of `Vm_Int` and `Vm_Ext`. |
| `LIFeling_vm_<suffix>_results.txt` | Text report containing configuration, paths, trace list, min/max/end values, event counts, reset timing, and VDD sag. |
| `LIFeling_vm_<suffix>.ngspice.log` | Raw ngspice log. Check this first when a run fails. |

The `<suffix>` is intentionally compact and includes a short hash so different simulation configurations do not overwrite each other.

Note: the committed example PNGs in this repository may still use the old `spiky_vm_...` prefix. Current versions of `Spice.py` write new normal-run files as `LIFeling_vm_...`.

---

## 13. Example plots from `LIFeling_pyspice_output/`

The repository contains committed PNG examples in:

```text
SPICE/LIFeling_pyspice_output/
```

The example plot files below were generated before the final filename-prefix rename, so their filenames still begin with `spiky_vm_...`. They are still valid examples of the LIFeling SPICE output folder. Current versions of `Spice.py` write new outputs with the `LIFeling_vm_...` prefix.

### 13.1 Baseline LIF output: `Vm_Int` vs `Vm_Ext`

This is the cleanest first plot to show in the README because it compares the internal membrane node with the external/live output path.

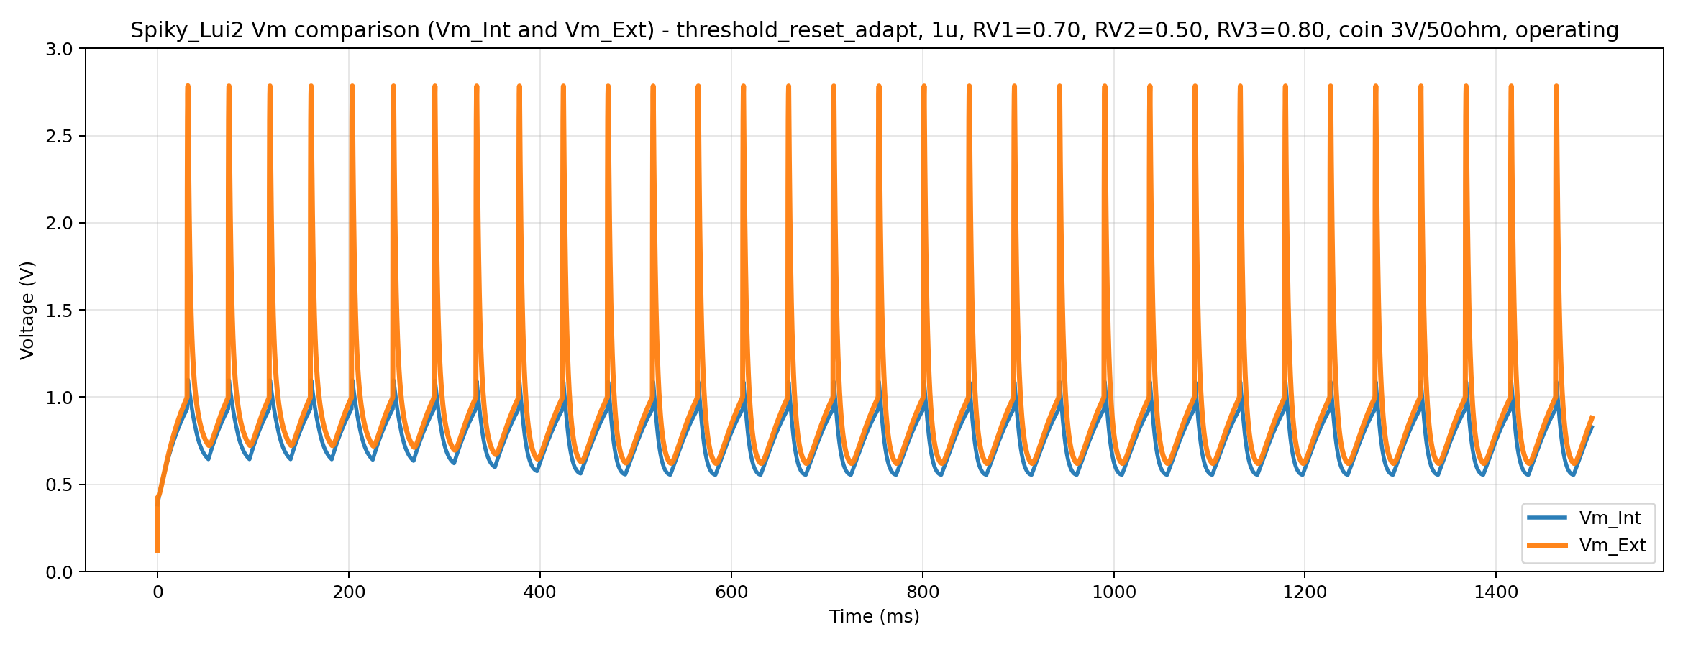
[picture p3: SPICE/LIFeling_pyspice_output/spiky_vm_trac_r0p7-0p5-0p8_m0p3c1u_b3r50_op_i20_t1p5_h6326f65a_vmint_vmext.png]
Baseline LIFeling Vm_Int and Vm_Ext comparison


Corresponding full multi-trace diagnostic plot:

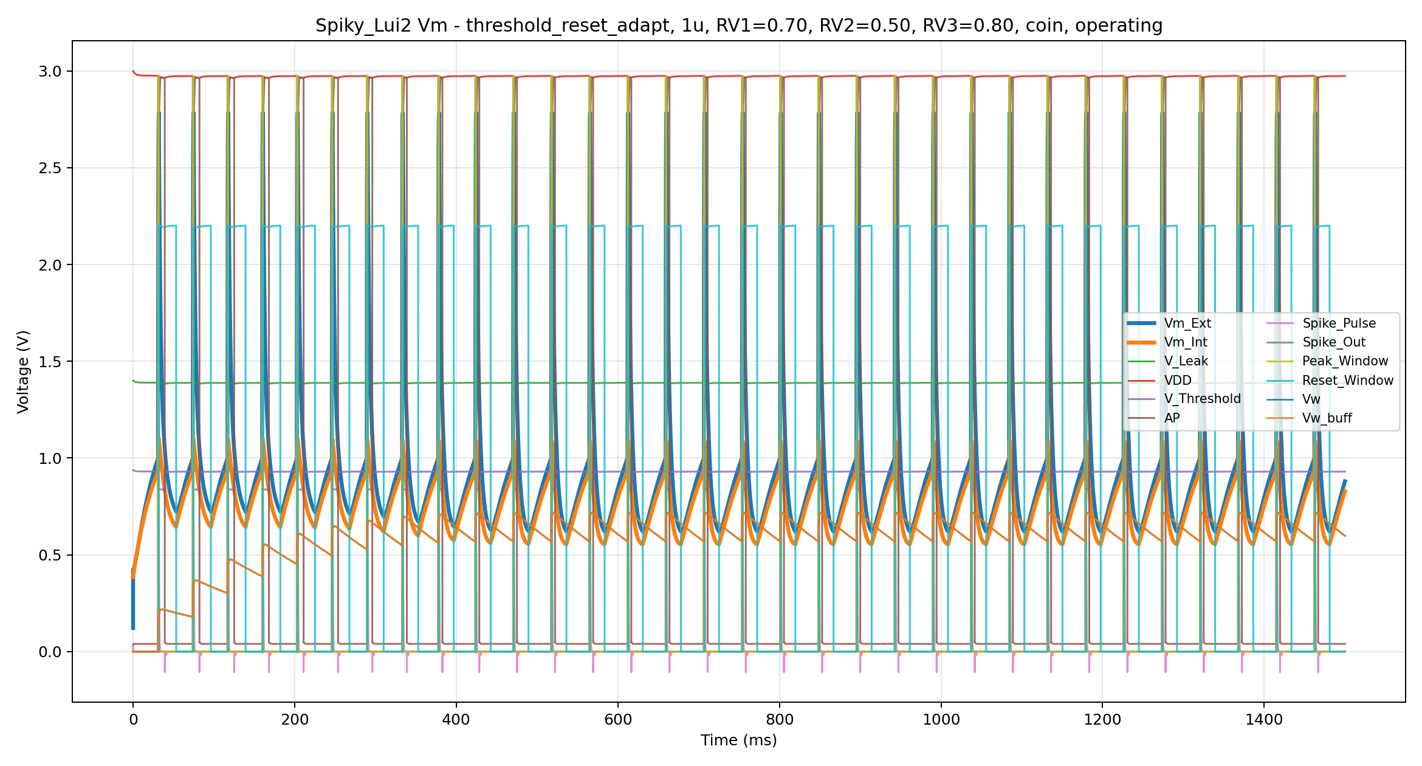
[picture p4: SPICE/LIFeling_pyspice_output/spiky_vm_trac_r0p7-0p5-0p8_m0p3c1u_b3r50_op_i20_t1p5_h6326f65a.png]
Baseline LIFeling full diagnostic traces


This example corresponds to a full `threshold_reset_adapt` run using RV1/RV2/RV3 = `0.7/0.5/0.8`, RV4-selected membrane capacitance, a simplified 3 V coin-cell supply with 50 ohm source resistance, operating startup mode, and 20 ms ignored startup.

### 13.2 Debug trace example

This plot uses the debug trace set and is useful when diagnosing reset, peak injection, reference, or internal control nodes.

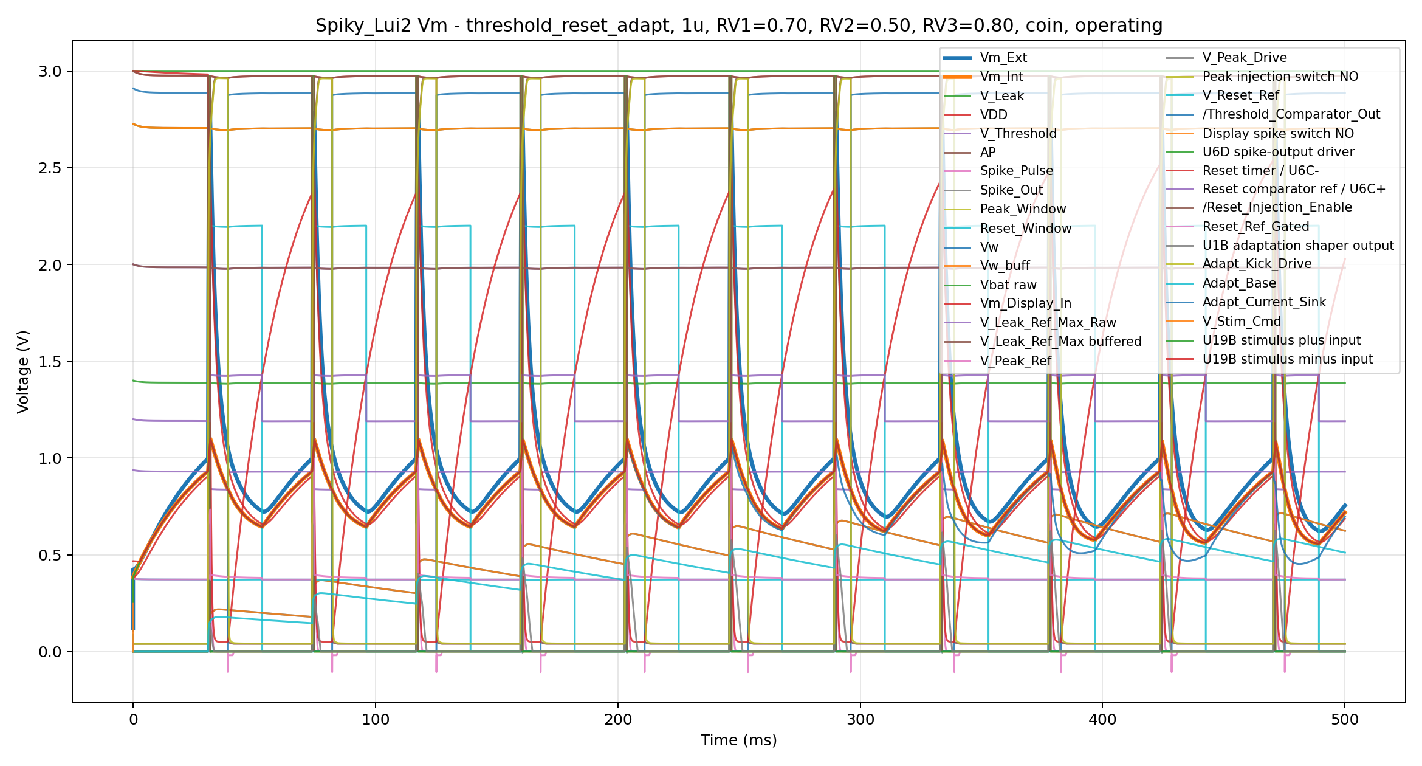
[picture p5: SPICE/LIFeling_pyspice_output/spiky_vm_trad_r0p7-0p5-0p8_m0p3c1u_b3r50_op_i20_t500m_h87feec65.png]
LIFeling debug trace example


Use this type of plot when the baseline `Vm_Ext` output looks wrong and you need to inspect internal nodes.

### 13.3 Synaptic response example

This example enables all four synaptic inputs with staggered pulse timings.

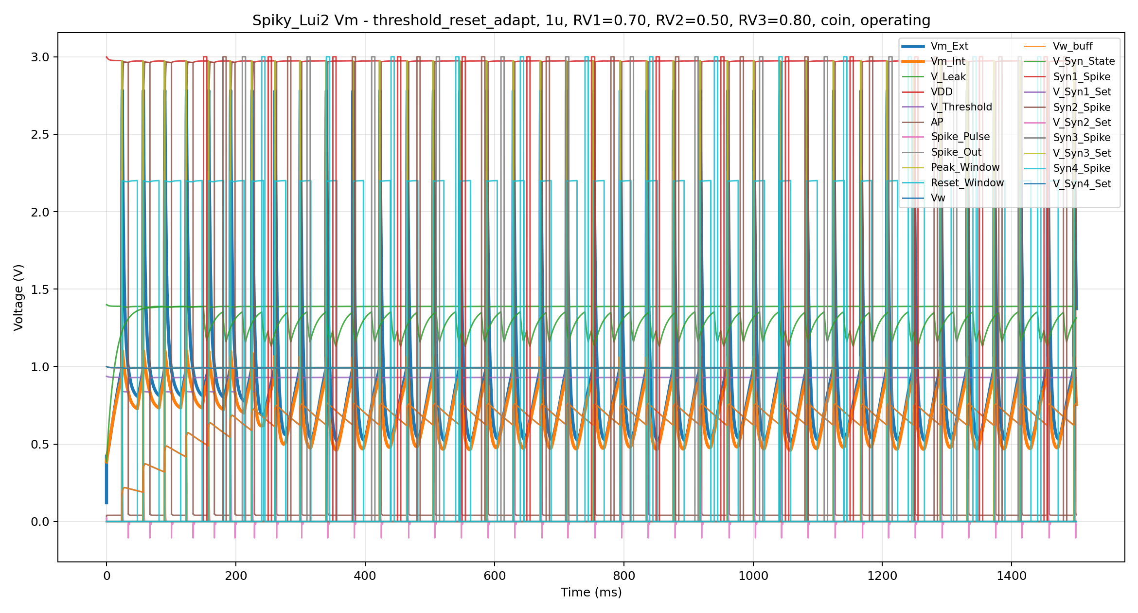
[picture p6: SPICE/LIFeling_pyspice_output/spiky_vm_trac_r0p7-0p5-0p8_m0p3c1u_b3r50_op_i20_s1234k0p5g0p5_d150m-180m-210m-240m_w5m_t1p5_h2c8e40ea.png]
LIFeling synaptic response diagnostic traces


Corresponding `Vm_Int` / `Vm_Ext` comparison:

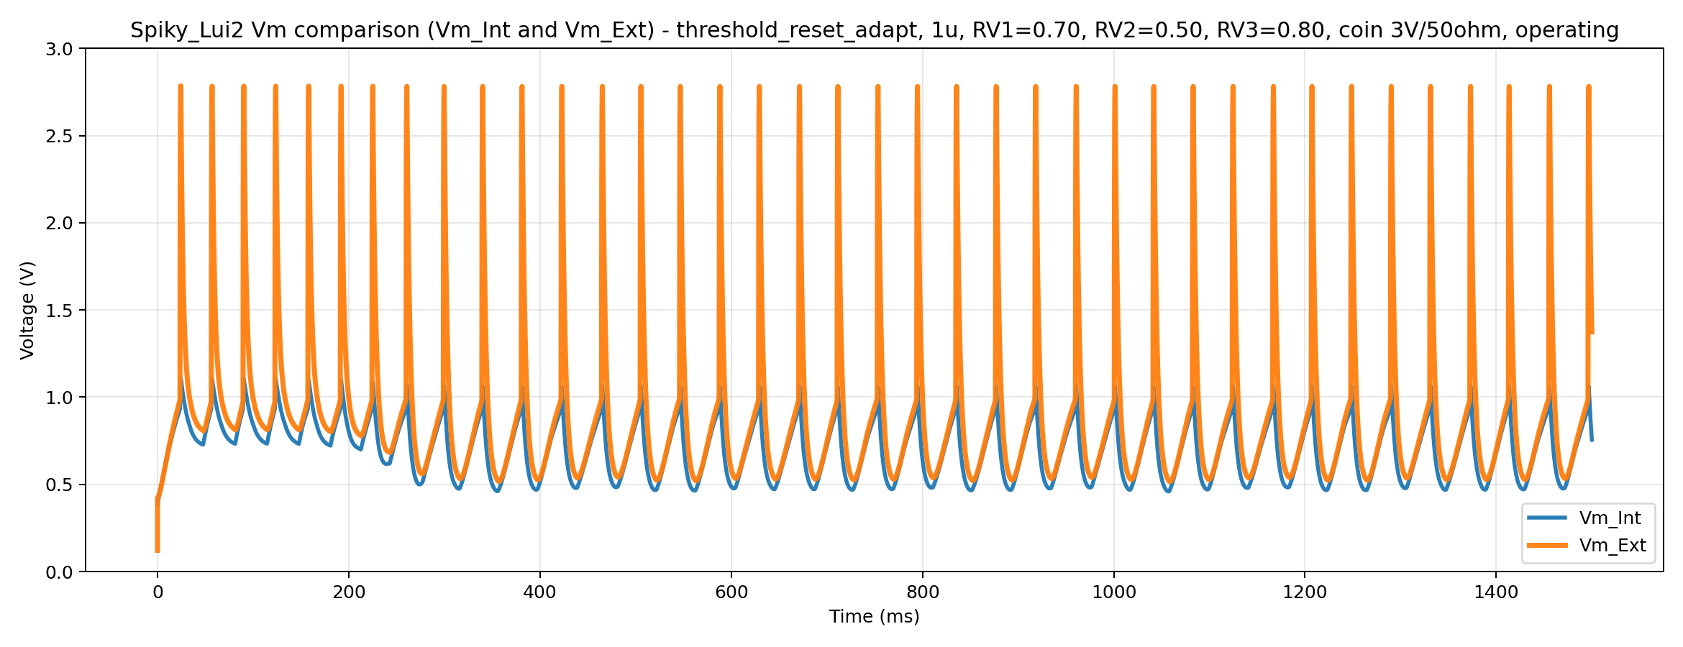
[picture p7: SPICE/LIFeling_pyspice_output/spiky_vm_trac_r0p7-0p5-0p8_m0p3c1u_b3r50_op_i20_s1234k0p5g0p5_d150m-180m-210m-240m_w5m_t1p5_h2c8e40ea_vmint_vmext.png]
LIFeling synaptic Vm_Int and Vm_Ext comparison


Use this plot when checking RV5 synaptic decay, RV6-RV9 set voltages, and the `V_Syn_State -> V_Syn_Drive -> Vm_Int` path.

### 13.4 Stimulus-path example

This plot shows a debug run with a positive DC stimulus command.

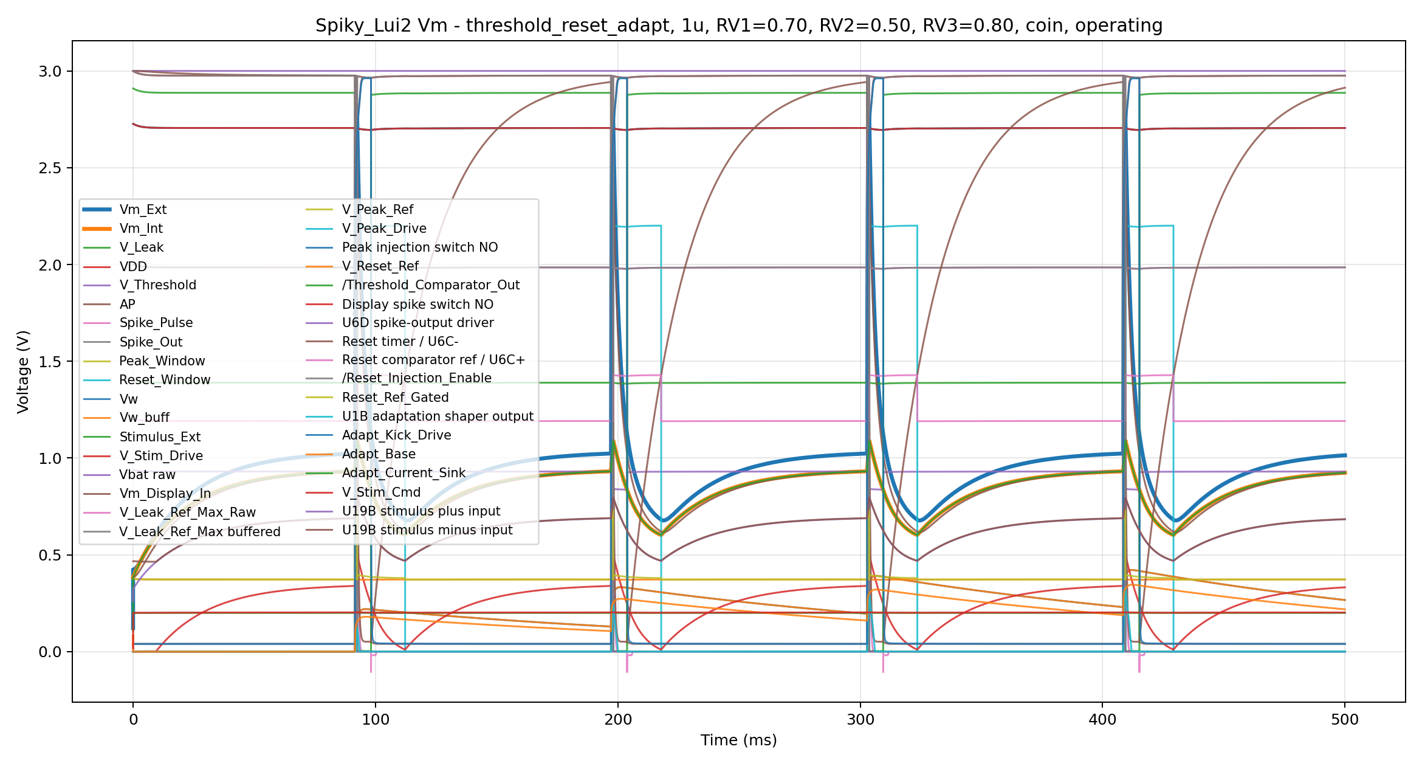
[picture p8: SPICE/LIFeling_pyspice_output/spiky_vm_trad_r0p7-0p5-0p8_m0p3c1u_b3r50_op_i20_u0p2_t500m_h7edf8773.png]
LIFeling stimulus path debug example


Use this plot to check that the `Stimulus_Ext -> U19B equivalent -> Vm_Int` path affects the membrane as expected.

### 13.5 Cold-start example

This example shows the same full LIF path under cold-start initial conditions.

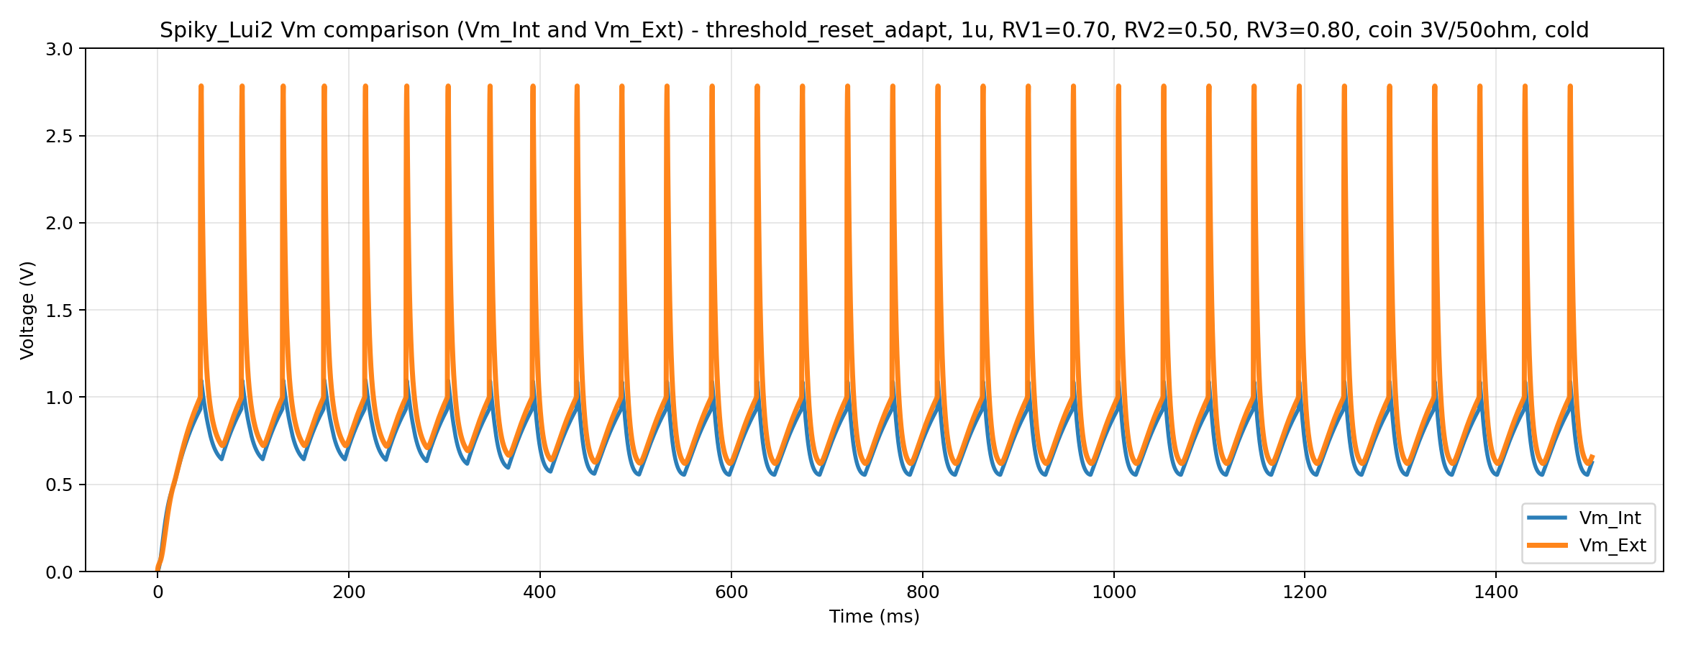
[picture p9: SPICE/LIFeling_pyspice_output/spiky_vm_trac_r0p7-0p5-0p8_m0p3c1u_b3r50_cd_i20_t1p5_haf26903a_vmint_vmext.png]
LIFeling cold-start Vm_Int and Vm_Ext comparison


Cold-start plots are useful for separating normal operating behaviour from power-on transients.

---

## 14. How to interpret results

Open the generated text report first:

```text
*_results.txt
```

It contains the run configuration, trace list, summary statistics, and event diagnostics.

### 14.1 `Vm_Ext`

`Vm_Ext` is the physically relevant live output trace.

A healthy full run should show:

- membrane-like charging,
- a visible spike-like peak during the peak/display window,
- reset and recovery,
- repeated events if the selected parameters produce oscillation.

The cleanest plot to inspect is:

```text
*_vmint_vmext.png
```

### 14.2 `Vm_Int`

`Vm_Int` is the internal membrane node.

Use it to distinguish between internal LIF behaviour and the display/live-output path.

If `Vm_Int` spikes but `Vm_Ext` does not, inspect:

```text
Vm_Int -> R90/C38 -> Vm_Display_In -> U8/R1/C14 -> Vm_Ext
```

If neither `Vm_Int` nor `Vm_Ext` spikes, inspect the peak injection path:

```text
V_Peak_Ref -> V_Peak_Drive -> R49/U14 -> Vm_Int
```

Use:

```text
--trace-set debug
```

to include `V_Peak_Ref`, `V_Peak_Drive`, and the peak-injection switch node.

### 14.3 Threshold and spike counts

The report prints lines similar to:

```text
Threshold crossing count after ignore = ...
Spike_Pulse rising-edge count >1 V after ignore = ...
Reset_Window rising-edge count >1 V after ignore = ...
```

These counts should usually be similar. If they diverge strongly, one event-generation path is failing.

### 14.4 Reset window timing

The reset timing section reports:

```text
Reset_Window timing analysis >1 V after ignore:
  State at end = HIGH or LOW
  Duty cycle after ignore = ...
  Rising edges after ignore = ...
  Falling edges after ignore = ...
  Reset pulse width median = ...
  Reset pulse width max = ...
```

Important: `State at end = HIGH` does not automatically mean the circuit latched. The simulation may simply have stopped during a normal reset pulse.

A real latch concern is more likely if:

- `State at end = HIGH`,
- the open high pulse at the end is unusually long,
- falling edges are missing,
- reset pulse width is much larger than usual,
- Vm does not recover after reset.

### 14.5 VDD sag

When using `--supply-mode coin`, the report includes:

```text
VDD sag from Vbat = ... V
Approx peak battery current after ignore = ... mA
```

With:

```text
--vbat 3 --rbat 50
```

small VDD sag means the simulated circuit is not heavily loading the battery model. Large sag or oscillatory VDD behaviour means the chosen battery assumptions may be too weak or the simulated loading may be excessive.

### 14.6 Synaptic state

When synapses are enabled, inspect:

```text
V_Syn_State
V_Syn1_Set
V_Syn2_Set
V_Syn3_Set
V_Syn4_Set
```

Expected behaviour:

- low RV6-RV9 set values pull `V_Syn_State` lower,
- high RV6-RV9 set values push `V_Syn_State` higher,
- RV5 controls decay of `V_Syn_State` back toward `V_Leak`,
- the synaptic state should not permanently rail unless the run is an intentional stress test.

### 14.7 Buffered reference stability

In debug mode, inspect:

```text
V_Leak_Ref_Max_Raw
V_Leak_Ref_Max
```

The buffered node should remain stable under RV loading. If the raw node moves but the buffered node is stable, the buffer is doing its job. If both move only because VDD sags, that is expected under the simplified coin-cell model.

---

## 15. Built-in sweep mode

`Spice.py` includes an internal sweep mode:

```powershell
.\.venv\Scripts\python.exe .\Spice.py --sweep --stage threshold_reset_adapt --backend ngspice-cli --supply-mode coin --vbat 3 --rbat 50 --startup-mode operating --ignore-start-ms 20 --cmem-mode rv4 --rv4 0.3 --tstop 1.5 --tstep 1u --maxstep 1u
```

Default sweep values:

```text
RV1: 0.3, 0.5, 0.7, 1.0
RV2: 0.2, 0.5, 0.8
RV3: 0.2, 0.5, 0.8
```

Sweep outputs are written into:

```text
LIFeling_pyspice_output/sweep/
```

Typical sweep files:

```text
sweep_summary.csv
sweep_all_traces.csv
```

`Sweep_summary.csv` is usually the first file to inspect because it contains one row per run with key measurements and plot paths.

---

## 16. Suggested validation workflow after editing `Spice.py`

### Step 1: syntax check

```powershell
.\.venv\Scripts\python.exe -m py_compile .\Spice.py
```

### Step 2: short functional run

```powershell
.\.venv\Scripts\python.exe .\Spice.py --stage threshold_reset_adapt --backend ngspice-cli --ngspice-binary auto --trace-set core --supply-mode coin --vbat 3 --rbat 50 --startup-mode operating --ignore-start-ms 20 --rv1 0.7 --rv2 0.5 --rv3 0.8 --cmem-mode rv4 --rv4 0.3 --tstop 500m --tstep 1u --maxstep 1u
```

### Step 3: inspect outputs

Open:

```text
*_results.txt
*_vmint_vmext.png
*.ngspice.log
```

### Step 4: debug trace run if needed

```powershell
.\.venv\Scripts\python.exe .\Spice.py --stage threshold_reset_adapt --backend ngspice-cli --ngspice-binary auto --trace-set debug --supply-mode coin --vbat 3 --rbat 50 --startup-mode operating --ignore-start-ms 20 --rv1 0.7 --rv2 0.5 --rv3 0.8 --cmem-mode rv4 --rv4 0.3 --tstop 500m --tstep 1u --maxstep 1u
```

### Step 5: synaptic test

```powershell
.\.venv\Scripts\python.exe .\Spice.py --stage threshold_reset_adapt --backend ngspice-cli --ngspice-binary auto --trace-set debug --supply-mode coin --vbat 3 --rbat 50 --startup-mode operating --ignore-start-ms 20 --rv1 0.7 --rv2 0.5 --rv3 0.8 --cmem-mode rv4 --rv4 0.3 --syn-all-enable --rv5 0.5 --rv6 0.2 --rv7 0.4 --rv8 0.6 --rv9 0.8 --syn1-delay 150m --syn2-delay 180m --syn3-delay 210m --syn4-delay 240m --syn1-width 5m --syn2-width 5m --syn3-width 5m --syn4-width 5m --tstop 1.5 --tstep 1u --maxstep 1u
```

---

## 17. Practical pass/fail checklist

A normal full LIF run should show:

- `Vm_Ext` has a clear neuron-like spike/reset waveform.
- `Vm_Int` and `Vm_Ext` are consistent with the expected display/output path.
- Threshold crossing count, `Spike_Pulse` count, and `Reset_Window` count are broadly consistent.
- Reset pulses close again after opening.
- Reset pulse widths are stable.
- `VDD` sag is reasonable for the selected battery model.
- Synaptic runs move `V_Syn_State` in the expected direction.
- Debug runs show `V_Leak_Ref_Max_Raw` and buffered `V_Leak_Ref_Max` behaving as expected.
- The `.ngspice.log` file contains no fatal ngspice errors.

---

## 18. Common problems and fixes

### Problem: ngspice is not found

Pass the executable path explicitly:

```powershell
--ngspice-binary "C:/Users/mzimm/Documents/Spice64/bin/ngspice.exe"
```

or add the folder containing `ngspice.exe` to the Windows `PATH`.

### Problem: no CSV file is created

Open the matching `.ngspice.log` file.

Common causes:

- ngspice path is wrong,
- a saved node does not exist in the selected stage,
- a vendor model is missing in `--strict-vendor` mode,
- the vendor subcircuit pin order is wrong,
- convergence failed.

### Problem: generated filenames are too long

The script already uses shortened suffixes and a configuration hash, but Windows path limits can still be reached if the repository is deeply nested.

Move the repository closer to the drive root, for example:

```text
C:\GitHub\LIFeling\SPICE
```

### Problem: final `Reset_Window` is high

Do not immediately conclude that reset is latched. Check:

```text
Open high pulse at end duration
Reset pulse width median
Reset pulse width max
Rising edges after ignore
Falling edges after ignore
```

If rising and falling edges continue and pulse widths are stable, the transient probably ended during a normal reset pulse.

### Problem: `Vm_Ext` does not spike

Run with:

```text
--trace-set debug
```

Check:

```text
V_Peak_Ref
V_Peak_Drive
Peak_Window
Vm_Display_In
Vm_Int
Vm_Ext
```

If `Vm_Int` spikes but `Vm_Ext` does not, inspect the output/display path. If `Peak_Window` fires but `Vm_Int` does not spike, inspect R49/U14 peak injection.

### Problem: synapses do not affect Vm

Check that at least one synapse is enabled:

```text
--syn1-enable
```

or:

```text
--syn-all-enable
```

Then inspect:

```text
Syn*_Spike
V_Syn*_Set
V_Syn_State
V_Syn_Drive
Vm_Int
```

Also confirm that the synaptic pulse occurs after the ignored startup interval set by `--ignore-start-ms`.

---

## 19. Reading the code

The main sections of `Spice.py` are:

| Section | Purpose |
|---|---|
| User-editable model configuration | Paths and names for optional vendor models. |
| SPICE-safe aliases | Maps schematic/KiCad concepts to SPICE-safe node names. |
| Trace definitions | Defines core and debug traces. |
| `SimConfig` | Stores all command-line options. |
| Selection/naming helpers | Capacitance selection, output suffixes, timing tags, hashes. |
| Generic utilities | SPICE suffix parsing, tolerance handling, path handling. |
| Model includes/wrappers | Fallback models and optional strict-vendor support. |
| Netlist generation | Adds supply, references, membrane, threshold, reset, adaptation, stimulus, synapses, and output path. |
| Simulation runners | Runs ngspice CLI or PySpice. |
| Plotting and diagnostics | Creates PNGs and writes event/timing/power summaries. |
| Sweep helpers | Runs parameter sweeps and writes summary CSVs. |
| Command-line parser | Defines the CLI interface. |

The most important circuit-building functions are:

| Function | Adds |
|---|---|
| `add_supply_and_decoupling()` | Ideal or coin-cell supply model. |
| `add_references_and_passive_vm()` | Buffered leak reference, RV1/RV2, membrane capacitor, clamps. |
| `add_external_stimulus()` | Stimulus input path and U19B equivalent. |
| `add_threshold()` | U6B threshold comparator and AP/spike-pulse path. |
| `add_peak_and_reset()` | Peak injection, reset windows, reset current, `Spike_Out`. |
| `add_adaptation()` | Adaptation path and Q2 sink. |
| `add_synaptic_circuits()` | Synaptic set voltages, input switches, state decay, and injection. |
| `add_vm_external_output()` | `Vm_Ext` display/live-output path. |
| `build_spice_deck()` | Assembles the final SPICE deck. |

---

## 20. Notes for future contributors

When adding or updating schematic blocks:

1. Use schematic-like component names where possible.
2. Use SPICE-safe node names and comment the original KiCad net name.
3. Keep `core` traces compact and readable.
4. Put internal diagnostic nodes in the `debug` trace set.
5. Keep output filenames short; rely on the hash for uniqueness.
6. Add an explicit test command to this README when a new block becomes important.
7. Keep `*_results.txt` useful for non-coders: it should explain enough for a user to decide whether a run passed.
8. When committing example PNG plots, link them with exact relative Markdown paths and avoid wildcards.

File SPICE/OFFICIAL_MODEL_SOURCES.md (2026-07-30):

# Official model-source register

The machine-readable authority is `model_registry.json`; this document is a reader-facing index. Downloaded packages are not trusted merely because the filename matches. The workflow records the checksum, inspects every actual `.SUBCKT` declaration, requires an approved wrapper terminal order, and requires an ngspice smoke test before strict-vendor use.

| Device | Official source/package | Intended use |
|---|---|---|
| MCP6004T-I/ST | Microchip AN1297 MCP6001/2/4 PSpice macro-model | Supplied `MCP6001.txt`; one instance per physical MCP6004 channel. |
| TLV7044PWR | TI `SLVMDH0.ZIP` | Inspect whether package is single/quad channel; preserve open-drain outputs and physical PW-14 mapping. |
| TLV7031DCKR | TI `SLVMDG0A.ZIP` | Push-pull comparator; DCK physical wrapper. |
| TLV9001IDBVR | TI TLV900x PSpice package (`SBOMAL2D.ZIP` currently identified) | Verify normal DBV pinout and channel extraction; do not substitute the U-pinout variant. |
| TLV9041IDBVR | TI `SBOMB62B.ZIP` | Verify normal TLV9041 DBV pinout and model declaration. |
| TS5A3166DCKR | TI `SCDJ032.ZIP` HSPICE model | Convert only after syntax and active-high control smoke tests. |
| TPS610995DRVR | TI `SLVMCO7A.ZIP` unencrypted transient model | Exact fixed 3.6 V variant; verify DRV terminal declaration and external L/C use. |
| REF3020AIDBZR | TI `SBVM736A.TSM` | Physical DBZ pins are verified; TINA terminal order and ngspice conversion remain gated. |
| TPD1E05U06DPYT | Exact catalog part exposes IBIS/S-parameter resources; TI Q1 variant has `SLVME60.ZIP` | Default remains a clearly labelled datasheet-derived transient clamp model. |

Discrete exact-vendor models remain conditional on the actual ordered manufacturer. The model manifest distinguishes exact matches, cross-manufacturer comparison files and datasheet-derived fallbacks.

## Strict-vendor adapter contract

After terminal orders are approved, create `models/vendor/vendor_adapters.lib` from the provided template. The strict deck includes this library instead of the portable library. The build fails if any required wrapper subcircuit or exact-device model card is missing. This prevents a nominal `vendor` profile from silently continuing to use portable models.

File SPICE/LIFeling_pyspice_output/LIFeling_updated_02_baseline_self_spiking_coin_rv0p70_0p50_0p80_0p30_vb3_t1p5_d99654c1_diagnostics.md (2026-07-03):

# LIFeling run diagnostics — 02_baseline_self_spiking_coin

Script version: `validation-suite-v4`
Analysis ignores first `20 ms`.

| Metric | Value |
|---|---:|
| `Vm_Int_min` | 0.463651 |
| `Vm_Int_max` | 0.883175 |
| `Vm_Int_end` | 0.726395 |
| `Vm_Ext_max` | 2.50194 |
| `V_Threshold_min` | 0.846917 |
| `V_Threshold_max` | 0.869245 |
| `Vm_threshold_crossings` | 27 |
| `Vm_first_threshold_crossing_ms` | 75.4917 |
| `AP_rising_edges` | 27 |
| `Spike_Pulse_rising_edges` | 27 |
| `Peak_Window_rising_edges` | 27 |
| `Reset_Window_rising_edges` | 27 |
| `Spike_Out_rising_edges` | 27 |
| `AP_mean_period_ms` | 53.8928 |
| `Reset_Window_mean_period_ms` | 53.8876 |
| `V_Syn_State_min` | 1.00804 |
| `V_Syn_State_max` | 1.0183 |
| `/V_Syn_Drive_min` | 0.447784 |
| `/V_Syn_Drive_max` | 0.877124 |
| `VDD_min` | 2.85117 |
| `VDD_sag_max` | 0.148833 |
| `Battery_current_peak_mA_est` | 2.97666 |

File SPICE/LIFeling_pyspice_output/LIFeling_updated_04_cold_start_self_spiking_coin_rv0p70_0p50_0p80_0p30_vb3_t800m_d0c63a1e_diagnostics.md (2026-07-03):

# LIFeling run diagnostics — 04_cold_start_self_spiking_coin

Script version: `validation-suite-v4`
Analysis ignores first `20 ms`.

| Metric | Value |
|---|---:|
| `Vm_Int_min` | 0.602352 |
| `Vm_Int_max` | 1.63221 |
| `Vm_Int_end` | 0.832469 |
| `Vm_Ext_max` | 2.56669 |
| `V_Threshold_min` | 0.846714 |
| `V_Threshold_max` | 0.868841 |
| `Vm_threshold_crossings` | 58 |
| `Vm_first_threshold_crossing_ms` | 27.0064 |
| `AP_rising_edges` | 58 |
| `Spike_Pulse_rising_edges` | 58 |
| `Peak_Window_rising_edges` | 58 |
| `Reset_Window_rising_edges` | 12 |
| `Spike_Out_rising_edges` | 58 |
| `AP_mean_period_ms` | 13.5355 |
| `Reset_Window_mean_period_ms` | 4.93607 |
| `V_Syn_State_min` | 0.787091 |
| `V_Syn_State_max` | 1.01933 |
| `/V_Syn_Drive_min` | 0.526993 |
| `/V_Syn_Drive_max` | 1.62158 |
| `VDD_min` | 2.90129 |
| `VDD_sag_max` | 0.0987118 |
| `Battery_current_peak_mA_est` | 1.97424 |

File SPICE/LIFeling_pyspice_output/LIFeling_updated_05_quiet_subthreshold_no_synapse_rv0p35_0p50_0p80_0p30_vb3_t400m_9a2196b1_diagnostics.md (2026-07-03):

# LIFeling run diagnostics — 05_quiet_subthreshold_no_synapse

Script version: `validation-suite-v4`
Analysis ignores first `20 ms`.

| Metric | Value |
|---|---:|
| `Vm_Int_min` | 0.29404 |
| `Vm_Int_max` | 0.509995 |
| `Vm_Int_end` | 0.509995 |
| `Vm_Ext_max` | 0.560895 |
| `V_Threshold_min` | 0.869216 |
| `V_Threshold_max` | 0.86926 |
| `Vm_threshold_crossings` | 0 |
| `Vm_first_threshold_crossing_ms` | nan |
| `AP_rising_edges` | 0 |
| `Spike_Pulse_rising_edges` | 0 |
| `Peak_Window_rising_edges` | 0 |
| `Reset_Window_rising_edges` | 0 |
| `Spike_Out_rising_edges` | 0 |
| `AP_mean_period_ms` | nan |
| `Reset_Window_mean_period_ms` | nan |
| `V_Syn_State_min` | 1.00435 |
| `V_Syn_State_max` | 1.00898 |
| `/V_Syn_Drive_min` | 0.275689 |
| `/V_Syn_Drive_max` | 0.495045 |
| `VDD_min` | 2.97669 |
| `VDD_sag_max` | 0.0233111 |
| `Battery_current_peak_mA_est` | 0.466223 |

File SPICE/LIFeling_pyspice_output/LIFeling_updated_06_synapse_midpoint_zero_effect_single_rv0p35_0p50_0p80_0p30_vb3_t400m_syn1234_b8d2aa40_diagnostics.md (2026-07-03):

# LIFeling run diagnostics — 06_synapse_midpoint_zero_effect_single

Script version: `validation-suite-v4`
Analysis ignores first `20 ms`.

| Metric | Value |
|---|---:|
| `Vm_Int_min` | 0.29404 |
| `Vm_Int_max` | 0.510732 |
| `Vm_Int_end` | 0.510093 |
| `Vm_Ext_max` | 0.561704 |
| `V_Threshold_min` | 0.869216 |
| `V_Threshold_max` | 0.86926 |
| `Vm_threshold_crossings` | 0 |
| `Vm_first_threshold_crossing_ms` | nan |
| `AP_rising_edges` | 0 |
| `Spike_Pulse_rising_edges` | 0 |
| `Peak_Window_rising_edges` | 0 |
| `Reset_Window_rising_edges` | 0 |
| `Spike_Out_rising_edges` | 0 |
| `AP_mean_period_ms` | nan |
| `Reset_Window_mean_period_ms` | nan |
| `V_Syn_State_min` | 1.00435 |
| `V_Syn_State_max` | 1.01753 |
| `/V_Syn_Drive_min` | 0.275689 |
| `/V_Syn_Drive_max` | 0.503696 |
| `VDD_min` | 2.97669 |
| `VDD_sag_max` | 0.0233111 |
| `Battery_current_peak_mA_est` | 0.466223 |

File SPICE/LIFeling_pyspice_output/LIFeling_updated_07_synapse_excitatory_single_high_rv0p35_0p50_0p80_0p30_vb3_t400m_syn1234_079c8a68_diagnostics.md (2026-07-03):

# LIFeling run diagnostics — 07_synapse_excitatory_single_high

Script version: `validation-suite-v4`
Analysis ignores first `20 ms`.

| Metric | Value |
|---|---:|
| `Vm_Int_min` | 0.29404 |
| `Vm_Int_max` | 0.628322 |
| `Vm_Int_end` | 0.51666 |
| `Vm_Ext_max` | 0.690386 |
| `V_Threshold_min` | 0.869216 |
| `V_Threshold_max` | 0.86926 |
| `Vm_threshold_crossings` | 0 |
| `Vm_first_threshold_crossing_ms` | nan |
| `AP_rising_edges` | 0 |
| `Spike_Pulse_rising_edges` | 0 |
| `Peak_Window_rising_edges` | 0 |
| `Reset_Window_rising_edges` | 0 |
| `Spike_Out_rising_edges` | 0 |
| `AP_mean_period_ms` | nan |
| `Reset_Window_mean_period_ms` | nan |
| `V_Syn_State_min` | 1.00435 |
| `V_Syn_State_max` | 1.60302 |
| `/V_Syn_Drive_min` | 0.275689 |
| `/V_Syn_Drive_max` | 1.19168 |
| `VDD_min` | 2.97669 |
| `VDD_sag_max` | 0.0233111 |
| `Battery_current_peak_mA_est` | 0.466223 |

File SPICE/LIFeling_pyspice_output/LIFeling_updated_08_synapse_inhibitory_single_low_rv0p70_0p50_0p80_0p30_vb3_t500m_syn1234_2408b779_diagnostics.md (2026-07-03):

# LIFeling run diagnostics — 08_synapse_inhibitory_single_low

Script version: `validation-suite-v4`
Analysis ignores first `20 ms`.

| Metric | Value |
|---|---:|
| `Vm_Int_min` | 0.463651 |
| `Vm_Int_max` | 0.883175 |
| `Vm_Int_end` | 0.843489 |
| `Vm_Ext_max` | 2.5026 |
| `V_Threshold_min` | 0.846917 |
| `V_Threshold_max` | 0.869376 |
| `Vm_threshold_crossings` | 7 |
| `Vm_first_threshold_crossing_ms` | 75.4917 |
| `AP_rising_edges` | 7 |
| `Spike_Pulse_rising_edges` | 7 |
| `Peak_Window_rising_edges` | 7 |
| `Reset_Window_rising_edges` | 7 |
| `Spike_Out_rising_edges` | 7 |
| `AP_mean_period_ms` | 70.0308 |
| `Reset_Window_mean_period_ms` | 70.0078 |
| `V_Syn_State_min` | 0.437209 |
| `V_Syn_State_max` | 1.0183 |
| `/V_Syn_Drive_min` | 0.162138 |
| `/V_Syn_Drive_max` | 0.877138 |
| `VDD_min` | 2.85117 |
| `VDD_sag_max` | 0.148829 |
| `Battery_current_peak_mA_est` | 2.97658 |

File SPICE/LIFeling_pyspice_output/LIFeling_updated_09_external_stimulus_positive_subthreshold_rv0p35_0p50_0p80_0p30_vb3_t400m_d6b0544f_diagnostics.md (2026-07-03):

# LIFeling run diagnostics — 09_external_stimulus_positive_subthreshold

Script version: `validation-suite-v4`
Analysis ignores first `20 ms`.

| Metric | Value |
|---|---:|
| `Vm_Int_min` | 0.290149 |
| `Vm_Int_max` | 0.44804 |
| `Vm_Int_end` | 0.44804 |
| `Vm_Ext_max` | 0.49278 |
| `V_Threshold_min` | 0.869216 |
| `V_Threshold_max` | 0.869259 |
| `Vm_threshold_crossings` | 0 |
| `Vm_first_threshold_crossing_ms` | nan |
| `AP_rising_edges` | 0 |
| `Spike_Pulse_rising_edges` | 0 |
| `Peak_Window_rising_edges` | 0 |
| `Reset_Window_rising_edges` | 0 |
| `Spike_Out_rising_edges` | 0 |
| `AP_mean_period_ms` | nan |
| `Reset_Window_mean_period_ms` | nan |
| `V_Syn_State_min` | 1.00419 |
| `V_Syn_State_max` | 1.00718 |
| `/V_Syn_Drive_min` | 0.271751 |
| `/V_Syn_Drive_max` | 0.431294 |
| `VDD_min` | 2.97669 |
| `VDD_sag_max` | 0.0233119 |
| `Battery_current_peak_mA_est` | 0.466238 |

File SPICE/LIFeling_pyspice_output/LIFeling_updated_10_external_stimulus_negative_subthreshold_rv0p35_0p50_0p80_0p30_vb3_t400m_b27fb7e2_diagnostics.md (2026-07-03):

# LIFeling run diagnostics — 10_external_stimulus_negative_subthreshold

Script version: `validation-suite-v4`
Analysis ignores first `20 ms`.

| Metric | Value |
|---|---:|
| `Vm_Int_min` | 0.282585 |
| `Vm_Int_max` | 0.424878 |
| `Vm_Int_end` | 0.424878 |
| `Vm_Ext_max` | 0.467317 |
| `V_Threshold_min` | 0.869216 |
| `V_Threshold_max` | 0.869259 |
| `Vm_threshold_crossings` | 0 |
| `Vm_first_threshold_crossing_ms` | nan |
| `AP_rising_edges` | 0 |
| `Spike_Pulse_rising_edges` | 0 |
| `Peak_Window_rising_edges` | 0 |
| `Reset_Window_rising_edges` | 0 |
| `Spike_Out_rising_edges` | 0 |
| `AP_mean_period_ms` | nan |
| `Reset_Window_mean_period_ms` | nan |
| `V_Syn_State_min` | 1.00394 |
| `V_Syn_State_max` | 1.0065 |
| `/V_Syn_Drive_min` | 0.264075 |
| `/V_Syn_Drive_max` | 0.407459 |
| `VDD_min` | 2.97669 |
| `VDD_sag_max` | 0.023312 |
| `Battery_current_peak_mA_est` | 0.46624 |

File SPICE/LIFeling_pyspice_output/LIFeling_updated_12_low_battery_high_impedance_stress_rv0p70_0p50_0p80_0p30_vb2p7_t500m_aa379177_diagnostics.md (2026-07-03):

# LIFeling run diagnostics — 12_low_battery_high_impedance_stress

Script version: `validation-suite-v4`
Analysis ignores first `20 ms`.

| Metric | Value |
|---|---:|
| `Vm_Int_min` | 0.609711 |
| `Vm_Int_max` | 1.46373 |
| `Vm_Int_end` | 0.834982 |
| `Vm_Ext_max` | 1.80077 |
| `V_Threshold_min` | 0.846916 |
| `V_Threshold_max` | 0.866152 |
| `Vm_threshold_crossings` | 52 |
| `Vm_first_threshold_crossing_ms` | 20.0039 |
| `AP_rising_edges` | 52 |
| `Spike_Pulse_rising_edges` | 0 |
| `Peak_Window_rising_edges` | 52 |
| `Reset_Window_rising_edges` | 15 |
| `Spike_Out_rising_edges` | 52 |
| `AP_mean_period_ms` | 9.27388 |
| `Reset_Window_mean_period_ms` | 5.47064 |
| `V_Syn_State_min` | 1.01499 |
| `V_Syn_State_max` | 1.01898 |
| `/V_Syn_Drive_min` | 0.600762 |
| `/V_Syn_Drive_max` | 1.45864 |
| `VDD_min` | 2.51807 |
| `VDD_sag_max` | 0.181931 |
| `Battery_current_peak_mA_est` | 1.5161 |

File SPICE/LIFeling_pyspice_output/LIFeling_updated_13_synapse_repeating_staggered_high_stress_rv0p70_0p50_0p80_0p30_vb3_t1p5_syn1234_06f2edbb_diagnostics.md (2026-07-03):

# LIFeling run diagnostics — 13_synapse_repeating_staggered_high_stress

Script version: `validation-suite-v4`
Analysis ignores first `20 ms`.

| Metric | Value |
|---|---:|
| `Vm_Int_min` | 0.463651 |
| `Vm_Int_max` | 0.893552 |
| `Vm_Int_end` | 0.846796 |
| `Vm_Ext_max` | 2.50194 |
| `V_Threshold_min` | 0.846917 |
| `V_Threshold_max` | 0.869431 |
| `Vm_threshold_crossings` | 37 |
| `Vm_first_threshold_crossing_ms` | 75.4917 |
| `AP_rising_edges` | 37 |
| `Spike_Pulse_rising_edges` | 37 |
| `Peak_Window_rising_edges` | 37 |
| `Reset_Window_rising_edges` | 37 |
| `Spike_Out_rising_edges` | 37 |
| `AP_mean_period_ms` | 39.4675 |
| `Reset_Window_mean_period_ms` | 39.459 |
| `V_Syn_State_min` | 1.00804 |
| `V_Syn_State_max` | 1.68133 |
| `/V_Syn_Drive_min` | 0.447784 |
| `/V_Syn_Drive_max` | 1.54233 |
| `VDD_min` | 2.84369 |
| `VDD_sag_max` | 0.156309 |
| `Battery_current_peak_mA_est` | 3.12618 |

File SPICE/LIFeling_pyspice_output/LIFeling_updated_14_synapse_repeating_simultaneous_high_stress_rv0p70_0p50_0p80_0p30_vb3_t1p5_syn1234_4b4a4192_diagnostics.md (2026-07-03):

# LIFeling run diagnostics — 14_synapse_repeating_simultaneous_high_stress

Script version: `validation-suite-v4`
Analysis ignores first `20 ms`.

| Metric | Value |
|---|---:|
| `Vm_Int_min` | 0.463651 |
| `Vm_Int_max` | 0.900929 |
| `Vm_Int_end` | 0.850568 |
| `Vm_Ext_max` | 2.50194 |
| `V_Threshold_min` | 0.846917 |
| `V_Threshold_max` | 0.869264 |
| `Vm_threshold_crossings` | 30 |
| `Vm_first_threshold_crossing_ms` | 75.4917 |
| `AP_rising_edges` | 30 |
| `Spike_Pulse_rising_edges` | 30 |
| `Peak_Window_rising_edges` | 30 |
| `Reset_Window_rising_edges` | 30 |
| `Spike_Out_rising_edges` | 30 |
| `AP_mean_period_ms` | 48.9903 |
| `Reset_Window_mean_period_ms` | 48.9814 |
| `V_Syn_State_min` | 1.00804 |
| `V_Syn_State_max` | 1.94909 |
| `/V_Syn_Drive_min` | 0.447784 |
| `/V_Syn_Drive_max` | 1.81744 |
| `VDD_min` | 2.84051 |
| `VDD_sag_max` | 0.159487 |
| `Battery_current_peak_mA_est` | 3.18975 |

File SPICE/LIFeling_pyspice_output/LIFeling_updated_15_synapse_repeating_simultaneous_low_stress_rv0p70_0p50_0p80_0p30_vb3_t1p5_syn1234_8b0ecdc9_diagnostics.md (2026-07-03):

# LIFeling run diagnostics — 15_synapse_repeating_simultaneous_low_stress

Script version: `validation-suite-v4`
Analysis ignores first `20 ms`.

| Metric | Value |
|---|---:|
| `Vm_Int_min` | 0.463651 |
| `Vm_Int_max` | 0.883175 |
| `Vm_Int_end` | 0.879447 |
| `Vm_Ext_max` | 2.5029 |
| `V_Threshold_min` | 0.846917 |
| `V_Threshold_max` | 0.869245 |
| `Vm_threshold_crossings` | 16 |
| `Vm_first_threshold_crossing_ms` | 75.4917 |
| `AP_rising_edges` | 16 |
| `Spike_Pulse_rising_edges` | 16 |
| `Peak_Window_rising_edges` | 16 |
| `Reset_Window_rising_edges` | 15 |
| `Spike_Out_rising_edges` | 16 |
| `AP_mean_period_ms` | 94.9052 |
| `Reset_Window_mean_period_ms` | 94.5427 |
| `V_Syn_State_min` | 0.0976532 |
| `V_Syn_State_max` | 1.0183 |
| `/V_Syn_Drive_min` | 0.00156531 |
| `/V_Syn_Drive_max` | 0.877137 |
| `VDD_min` | 2.85117 |
| `VDD_sag_max` | 0.148829 |
| `Battery_current_peak_mA_est` | 2.97658 |

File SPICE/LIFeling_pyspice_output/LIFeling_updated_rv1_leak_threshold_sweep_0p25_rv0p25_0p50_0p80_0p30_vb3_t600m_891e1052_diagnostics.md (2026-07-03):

# LIFeling run diagnostics — rv1_leak_threshold_sweep_0p25

Script version: `validation-suite-v4`
Analysis ignores first `20 ms`.

| Metric | Value |
|---|---:|
| `Vm_Int_min` | 0.246941 |
| `Vm_Int_max` | 0.344901 |
| `Vm_Int_end` | 0.344901 |
| `Vm_Ext_max` | 0.379418 |
| `V_Threshold_min` | 0.869216 |
| `V_Threshold_max` | 0.869259 |
| `Vm_threshold_crossings` | 0 |
| `Vm_first_threshold_crossing_ms` | nan |
| `AP_rising_edges` | 0 |
| `Spike_Pulse_rising_edges` | 0 |
| `Peak_Window_rising_edges` | 0 |
| `Reset_Window_rising_edges` | 0 |
| `Spike_Out_rising_edges` | 0 |
| `AP_mean_period_ms` | nan |
| `Reset_Window_mean_period_ms` | nan |
| `V_Syn_State_min` | 1.00262 |
| `V_Syn_State_max` | 1.00486 |
| `/V_Syn_Drive_min` | 0.227891 |
| `/V_Syn_Drive_max` | 0.325163 |
| `VDD_min` | 2.97669 |
| `VDD_sag_max` | 0.023312 |
| `Battery_current_peak_mA_est` | 0.46624 |

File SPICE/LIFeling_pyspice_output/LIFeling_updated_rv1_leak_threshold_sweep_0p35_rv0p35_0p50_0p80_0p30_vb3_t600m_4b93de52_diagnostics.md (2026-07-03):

# LIFeling run diagnostics — rv1_leak_threshold_sweep_0p35

Script version: `validation-suite-v4`
Analysis ignores first `20 ms`.

| Metric | Value |
|---|---:|
| `Vm_Int_min` | 0.29404 |
| `Vm_Int_max` | 0.510042 |
| `Vm_Int_end` | 0.510042 |
| `Vm_Ext_max` | 0.560949 |
| `V_Threshold_min` | 0.869216 |
| `V_Threshold_max` | 0.86926 |
| `Vm_threshold_crossings` | 0 |
| `Vm_first_threshold_crossing_ms` | nan |
| `AP_rising_edges` | 0 |
| `Spike_Pulse_rising_edges` | 0 |
| `Peak_Window_rising_edges` | 0 |
| `Reset_Window_rising_edges` | 0 |
| `Spike_Out_rising_edges` | 0 |
| `AP_mean_period_ms` | nan |
| `Reset_Window_mean_period_ms` | nan |
| `V_Syn_State_min` | 1.00435 |
| `V_Syn_State_max` | 1.00898 |
| `/V_Syn_Drive_min` | 0.275689 |
| `/V_Syn_Drive_max` | 0.495094 |
| `VDD_min` | 2.97669 |
| `VDD_sag_max` | 0.0233111 |
| `Battery_current_peak_mA_est` | 0.466223 |

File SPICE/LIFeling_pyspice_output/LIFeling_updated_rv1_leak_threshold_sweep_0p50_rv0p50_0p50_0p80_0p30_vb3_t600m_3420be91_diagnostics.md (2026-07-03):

# LIFeling run diagnostics — rv1_leak_threshold_sweep_0p50

Script version: `validation-suite-v4`
Analysis ignores first `20 ms`.

| Metric | Value |
|---|---:|
| `Vm_Int_min` | 0.366019 |
| `Vm_Int_max` | 0.728062 |
| `Vm_Int_end` | 0.728062 |
| `Vm_Ext_max` | 0.80069 |
| `V_Threshold_min` | 0.869104 |
| `V_Threshold_max` | 0.869255 |
| `Vm_threshold_crossings` | 0 |
| `Vm_first_threshold_crossing_ms` | nan |
| `AP_rising_edges` | 0 |
| `Spike_Pulse_rising_edges` | 0 |
| `Peak_Window_rising_edges` | 0 |
| `Reset_Window_rising_edges` | 0 |
| `Spike_Out_rising_edges` | 0 |
| `AP_mean_period_ms` | nan |
| `Reset_Window_mean_period_ms` | nan |
| `V_Syn_State_min` | 1.00623 |
| `V_Syn_State_max` | 1.01533 |
| `/V_Syn_Drive_min` | 0.348726 |
| `/V_Syn_Drive_max` | 0.719439 |
| `VDD_min` | 2.96171 |
| `VDD_sag_max` | 0.0382923 |
| `Battery_current_peak_mA_est` | 0.765846 |

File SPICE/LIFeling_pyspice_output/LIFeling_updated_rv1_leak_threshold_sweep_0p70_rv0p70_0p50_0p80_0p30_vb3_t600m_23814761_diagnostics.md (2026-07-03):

# LIFeling run diagnostics — rv1_leak_threshold_sweep_0p70

Script version: `validation-suite-v4`
Analysis ignores first `20 ms`.

| Metric | Value |
|---|---:|
| `Vm_Int_min` | 0.463651 |
| `Vm_Int_max` | 0.883175 |
| `Vm_Int_end` | 0.815462 |
| `Vm_Ext_max` | 2.50194 |
| `V_Threshold_min` | 0.846917 |
| `V_Threshold_max` | 0.869245 |
| `Vm_threshold_crossings` | 10 |
| `Vm_first_threshold_crossing_ms` | 75.4917 |
| `AP_rising_edges` | 10 |
| `Spike_Pulse_rising_edges` | 10 |
| `Peak_Window_rising_edges` | 10 |
| `Reset_Window_rising_edges` | 10 |
| `Spike_Out_rising_edges` | 10 |
| `AP_mean_period_ms` | 53.7498 |
| `Reset_Window_mean_period_ms` | 53.735 |
| `V_Syn_State_min` | 1.00804 |
| `V_Syn_State_max` | 1.0183 |
| `/V_Syn_Drive_min` | 0.447784 |
| `/V_Syn_Drive_max` | 0.877124 |
| `VDD_min` | 2.85117 |
| `VDD_sag_max` | 0.148833 |
| `Battery_current_peak_mA_est` | 2.97666 |

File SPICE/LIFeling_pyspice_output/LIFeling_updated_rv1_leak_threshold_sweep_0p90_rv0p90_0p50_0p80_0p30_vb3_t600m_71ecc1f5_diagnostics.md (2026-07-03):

# LIFeling run diagnostics — rv1_leak_threshold_sweep_0p90

Script version: `validation-suite-v4`
Analysis ignores first `20 ms`.

| Metric | Value |
|---|---:|
| `Vm_Int_min` | 0.561935 |
| `Vm_Int_max` | 0.898 |
| `Vm_Int_end` | 0.722574 |
| `Vm_Ext_max` | 2.49971 |
| `V_Threshold_min` | 0.846917 |
| `V_Threshold_max` | 0.869235 |
| `Vm_threshold_crossings` | 18 |
| `Vm_first_threshold_crossing_ms` | 39.5929 |
| `AP_rising_edges` | 18 |
| `Spike_Pulse_rising_edges` | 18 |
| `Peak_Window_rising_edges` | 18 |
| `Reset_Window_rising_edges` | 18 |
| `Spike_Out_rising_edges` | 18 |
| `AP_mean_period_ms` | 31.6619 |
| `Reset_Window_mean_period_ms` | 31.6517 |
| `V_Syn_State_min` | 1.0095 |
| `V_Syn_State_max` | 1.01822 |
| `/V_Syn_Drive_min` | 0.547505 |
| `/V_Syn_Drive_max` | 0.889505 |
| `VDD_min` | 2.84096 |
| `VDD_sag_max` | 0.159042 |
| `Battery_current_peak_mA_est` | 3.18085 |

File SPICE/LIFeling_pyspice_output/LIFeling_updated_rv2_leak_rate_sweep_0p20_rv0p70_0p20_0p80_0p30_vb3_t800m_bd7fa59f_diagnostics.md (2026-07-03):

# LIFeling run diagnostics — rv2_leak_rate_sweep_0p20

Script version: `validation-suite-v4`
Analysis ignores first `20 ms`.

| Metric | Value |
|---|---:|
| `Vm_Int_min` | 0.35832 |
| `Vm_Int_max` | 0.794335 |
| `Vm_Int_end` | 0.794335 |
| `Vm_Ext_max` | 0.87357 |
| `V_Threshold_min` | 0.868857 |
| `V_Threshold_max` | 0.869254 |
| `Vm_threshold_crossings` | 0 |
| `Vm_first_threshold_crossing_ms` | nan |
| `AP_rising_edges` | 0 |
| `Spike_Pulse_rising_edges` | 0 |
| `Peak_Window_rising_edges` | 0 |
| `Reset_Window_rising_edges` | 0 |
| `Spike_Out_rising_edges` | 0 |
| `AP_mean_period_ms` | nan |
| `Reset_Window_mean_period_ms` | nan |
| `V_Syn_State_min` | 1.00605 |
| `V_Syn_State_max` | 1.01726 |
| `/V_Syn_Drive_min` | 0.340843 |
| `/V_Syn_Drive_max` | 0.787635 |
| `VDD_min` | 2.92869 |
| `VDD_sag_max` | 0.0713103 |
| `Battery_current_peak_mA_est` | 1.42621 |

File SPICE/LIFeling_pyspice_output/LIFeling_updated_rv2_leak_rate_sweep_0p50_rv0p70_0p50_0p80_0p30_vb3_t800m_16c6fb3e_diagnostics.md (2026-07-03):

# LIFeling run diagnostics — rv2_leak_rate_sweep_0p50

Script version: `validation-suite-v4`
Analysis ignores first `20 ms`.

| Metric | Value |
|---|---:|
| `Vm_Int_min` | 0.463651 |
| `Vm_Int_max` | 0.883175 |
| `Vm_Int_end` | 0.738965 |
| `Vm_Ext_max` | 2.50194 |
| `V_Threshold_min` | 0.846917 |
| `V_Threshold_max` | 0.869245 |
| `Vm_threshold_crossings` | 14 |
| `Vm_first_threshold_crossing_ms` | 75.4917 |
| `AP_rising_edges` | 14 |
| `Spike_Pulse_rising_edges` | 14 |
| `Peak_Window_rising_edges` | 14 |
| `Reset_Window_rising_edges` | 14 |
| `Spike_Out_rising_edges` | 14 |
| `AP_mean_period_ms` | 53.806 |
| `Reset_Window_mean_period_ms` | 53.7958 |
| `V_Syn_State_min` | 1.00804 |
| `V_Syn_State_max` | 1.0183 |
| `/V_Syn_Drive_min` | 0.447784 |
| `/V_Syn_Drive_max` | 0.877124 |
| `VDD_min` | 2.85117 |
| `VDD_sag_max` | 0.148833 |
| `Battery_current_peak_mA_est` | 2.97666 |

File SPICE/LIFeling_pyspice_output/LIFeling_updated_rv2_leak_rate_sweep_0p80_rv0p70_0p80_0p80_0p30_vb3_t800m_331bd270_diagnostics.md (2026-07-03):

# LIFeling run diagnostics — rv2_leak_rate_sweep_0p80

Script version: `validation-suite-v4`
Analysis ignores first `20 ms`.

| Metric | Value |
|---|---:|
| `Vm_Int_min` | 0.667107 |
| `Vm_Int_max` | 0.907063 |
| `Vm_Int_end` | 0.712138 |
| `Vm_Ext_max` | 2.49876 |
| `V_Threshold_min` | 0.846917 |
| `V_Threshold_max` | 0.869081 |
| `Vm_threshold_crossings` | 28 |
| `Vm_first_threshold_crossing_ms` | 23.1152 |
| `AP_rising_edges` | 28 |
| `Spike_Pulse_rising_edges` | 28 |
| `Peak_Window_rising_edges` | 28 |
| `Reset_Window_rising_edges` | 28 |
| `Spike_Out_rising_edges` | 28 |
| `AP_mean_period_ms` | 28.0669 |
| `Reset_Window_mean_period_ms` | 28.0706 |
| `V_Syn_State_min` | 1.01338 |
| `V_Syn_State_max` | 1.01901 |
| `/V_Syn_Drive_min` | 0.65874 |
| `/V_Syn_Drive_max` | 0.898172 |
| `VDD_min` | 2.83835 |
| `VDD_sag_max` | 0.16165 |
| `Battery_current_peak_mA_est` | 3.233 |

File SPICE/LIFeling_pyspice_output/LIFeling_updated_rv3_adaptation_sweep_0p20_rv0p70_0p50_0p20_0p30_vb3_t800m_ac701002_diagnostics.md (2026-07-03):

# LIFeling run diagnostics — rv3_adaptation_sweep_0p20

Script version: `validation-suite-v4`
Analysis ignores first `20 ms`.

| Metric | Value |
|---|---:|
| `Vm_Int_min` | 0.463651 |
| `Vm_Int_max` | 0.88323 |
| `Vm_Int_end` | 0.660942 |
| `Vm_Ext_max` | 2.50276 |
| `V_Threshold_min` | 0.846917 |
| `V_Threshold_max` | 0.869252 |
| `Vm_threshold_crossings` | 9 |
| `Vm_first_threshold_crossing_ms` | 75.4943 |
| `AP_rising_edges` | 9 |
| `Spike_Pulse_rising_edges` | 9 |
| `Peak_Window_rising_edges` | 9 |
| `Reset_Window_rising_edges` | 9 |
| `Spike_Out_rising_edges` | 9 |
| `AP_mean_period_ms` | 83.1223 |
| `Reset_Window_mean_period_ms` | 83.1276 |
| `V_Syn_State_min` | 1.00804 |
| `V_Syn_State_max` | 1.01844 |
| `/V_Syn_Drive_min` | 0.447784 |
| `/V_Syn_Drive_max` | 0.877134 |
| `VDD_min` | 2.85117 |
| `VDD_sag_max` | 0.14883 |
| `Battery_current_peak_mA_est` | 2.9766 |

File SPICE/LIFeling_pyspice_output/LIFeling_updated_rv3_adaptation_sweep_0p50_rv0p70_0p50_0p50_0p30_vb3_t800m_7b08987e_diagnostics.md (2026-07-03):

# LIFeling run diagnostics — rv3_adaptation_sweep_0p50

Script version: `validation-suite-v4`
Analysis ignores first `20 ms`.

| Metric | Value |
|---|---:|
| `Vm_Int_min` | 0.463651 |
| `Vm_Int_max` | 0.883227 |
| `Vm_Int_end` | 0.626693 |
| `Vm_Ext_max` | 2.50276 |
| `V_Threshold_min` | 0.846917 |
| `V_Threshold_max` | 0.869245 |
| `Vm_threshold_crossings` | 11 |
| `Vm_first_threshold_crossing_ms` | 75.4941 |
| `AP_rising_edges` | 11 |
| `Spike_Pulse_rising_edges` | 11 |
| `Peak_Window_rising_edges` | 11 |
| `Reset_Window_rising_edges` | 11 |
| `Spike_Out_rising_edges` | 11 |
| `AP_mean_period_ms` | 69.8488 |
| `Reset_Window_mean_period_ms` | 69.85 |
| `V_Syn_State_min` | 1.00804 |
| `V_Syn_State_max` | 1.01834 |
| `/V_Syn_Drive_min` | 0.447784 |
| `/V_Syn_Drive_max` | 0.87711 |
| `VDD_min` | 2.85117 |
| `VDD_sag_max` | 0.14883 |
| `Battery_current_peak_mA_est` | 2.97661 |

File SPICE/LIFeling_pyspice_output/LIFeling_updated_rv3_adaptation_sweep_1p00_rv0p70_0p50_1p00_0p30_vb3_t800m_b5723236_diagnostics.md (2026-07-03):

# LIFeling run diagnostics — rv3_adaptation_sweep_1p00

Script version: `validation-suite-v4`
Analysis ignores first `20 ms`.

| Metric | Value |
|---|---:|
| `Vm_Int_min` | 0.463651 |
| `Vm_Int_max` | 0.883203 |
| `Vm_Int_end` | 0.750654 |
| `Vm_Ext_max` | 2.50237 |
| `V_Threshold_min` | 0.846917 |
| `V_Threshold_max` | 0.869245 |
| `Vm_threshold_crossings` | 14 |
| `Vm_first_threshold_crossing_ms` | 75.4915 |
| `AP_rising_edges` | 14 |
| `Spike_Pulse_rising_edges` | 14 |
| `Peak_Window_rising_edges` | 14 |
| `Reset_Window_rising_edges` | 14 |
| `Spike_Out_rising_edges` | 14 |
| `AP_mean_period_ms` | 53.6841 |
| `Reset_Window_mean_period_ms` | 53.673 |
| `V_Syn_State_min` | 1.00804 |
| `V_Syn_State_max` | 1.0183 |
| `/V_Syn_Drive_min` | 0.447784 |
| `/V_Syn_Drive_max` | 0.877166 |
| `VDD_min` | 2.85116 |
| `VDD_sag_max` | 0.148837 |
| `Battery_current_peak_mA_est` | 2.97674 |

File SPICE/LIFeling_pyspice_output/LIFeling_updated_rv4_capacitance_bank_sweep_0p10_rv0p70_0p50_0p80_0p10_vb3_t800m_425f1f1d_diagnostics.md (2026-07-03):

# LIFeling run diagnostics — rv4_capacitance_bank_sweep_0p10

Script version: `validation-suite-v4`
Analysis ignores first `20 ms`.

| Metric | Value |
|---|---:|
| `Vm_Int_min` | 0.607784 |
| `Vm_Int_max` | 1.6328 |
| `Vm_Int_end` | 0.909359 |
| `Vm_Ext_max` | 2.56546 |
| `V_Threshold_min` | 0.846652 |
| `V_Threshold_max` | 0.868836 |
| `Vm_threshold_crossings` | 57 |
| `Vm_first_threshold_crossing_ms` | 20.0066 |
| `AP_rising_edges` | 57 |
| `Spike_Pulse_rising_edges` | 57 |
| `Peak_Window_rising_edges` | 57 |
| `Reset_Window_rising_edges` | 11 |
| `Spike_Out_rising_edges` | 57 |
| `AP_mean_period_ms` | 13.8329 |
| `Reset_Window_mean_period_ms` | 4.94108 |
| `V_Syn_State_min` | 1.01604 |
| `V_Syn_State_max` | 1.01933 |
| `/V_Syn_Drive_min` | 0.59987 |
| `/V_Syn_Drive_max` | 1.62591 |
| `VDD_min` | 2.90036 |
| `VDD_sag_max` | 0.0996377 |
| `Battery_current_peak_mA_est` | 1.99275 |

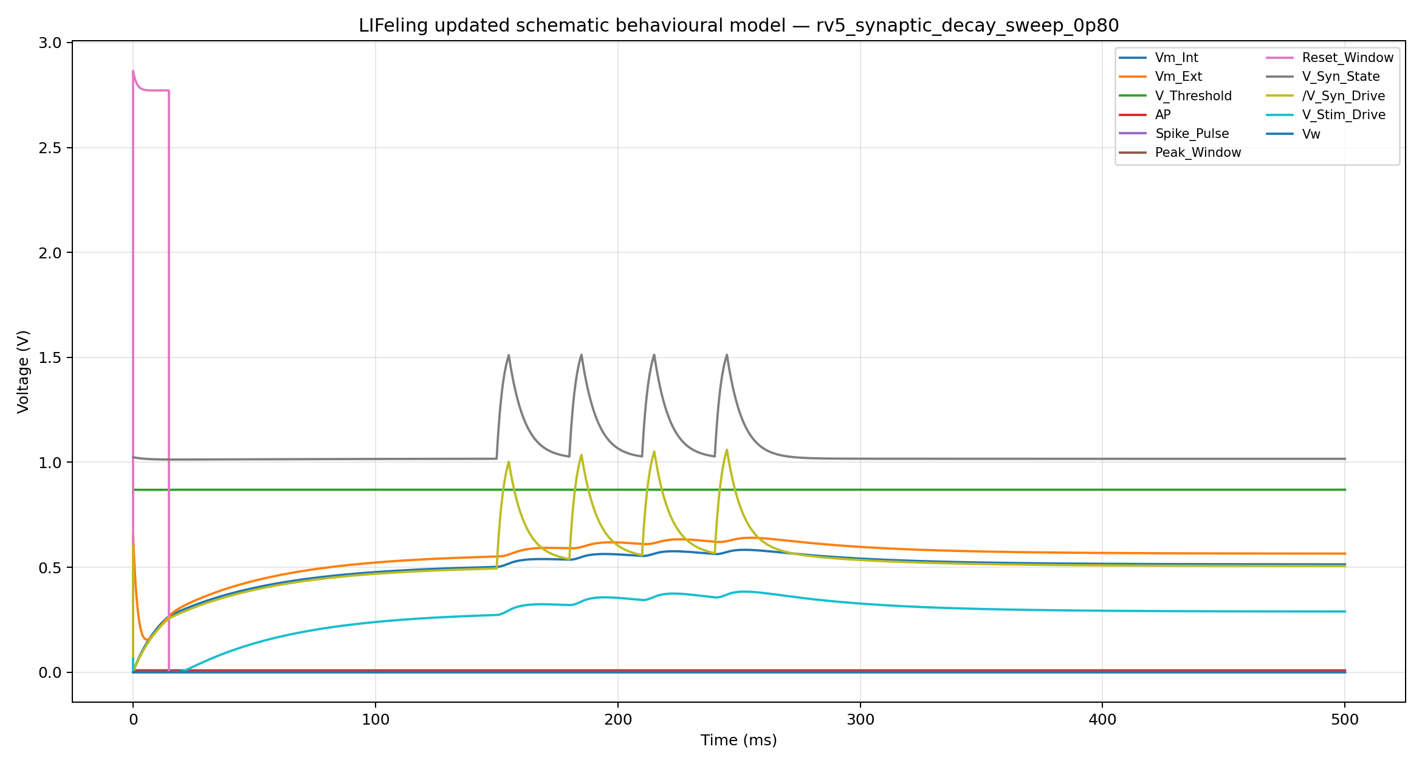
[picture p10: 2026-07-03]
SPICE/LIFeling_pyspice_output/LIFeling_updated_rv5_synaptic_decay_sweep_0p80_rv0p35_0p50_0p80_0p30_vb3_t500m_syn1234_b343df1e.png

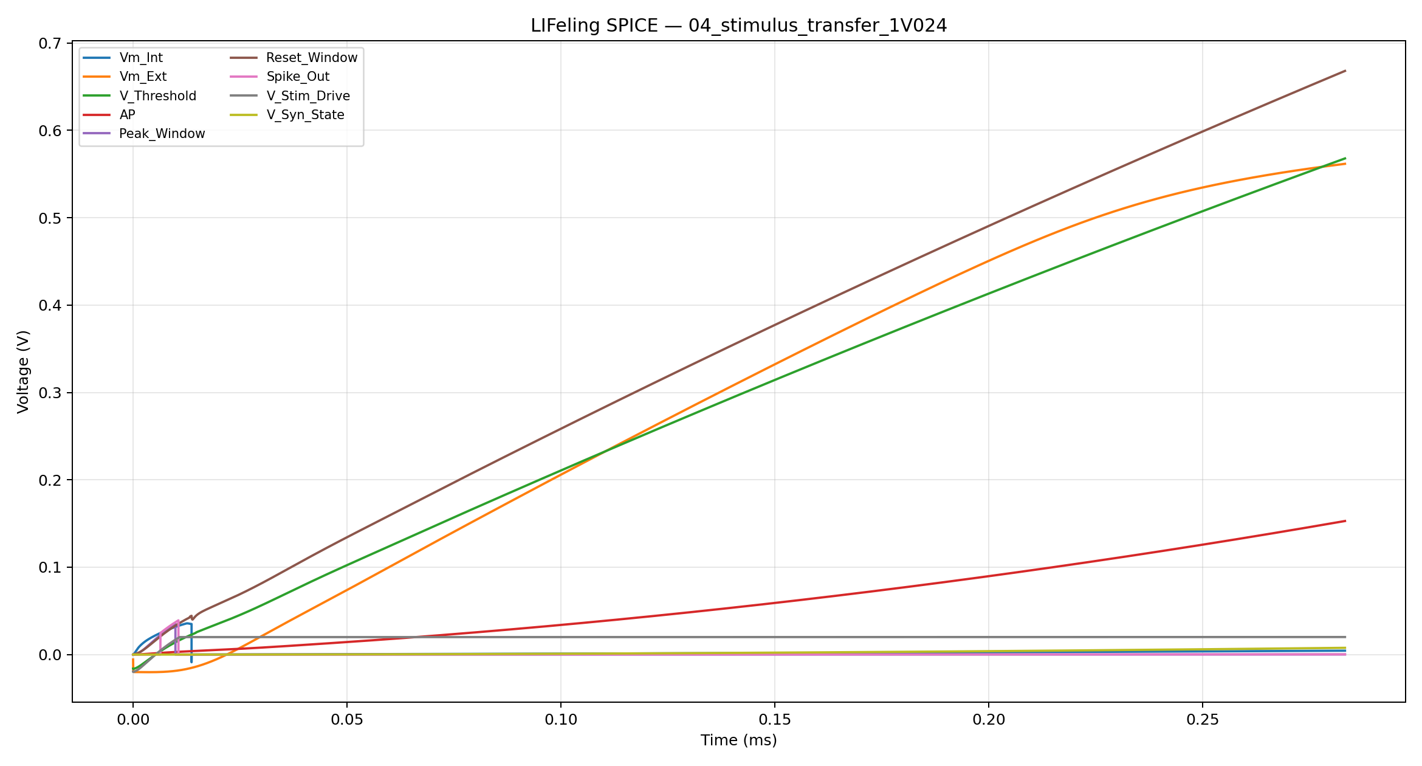
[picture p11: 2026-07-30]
SPICE/generated/N_04_stimulus_transfer_1V024.png

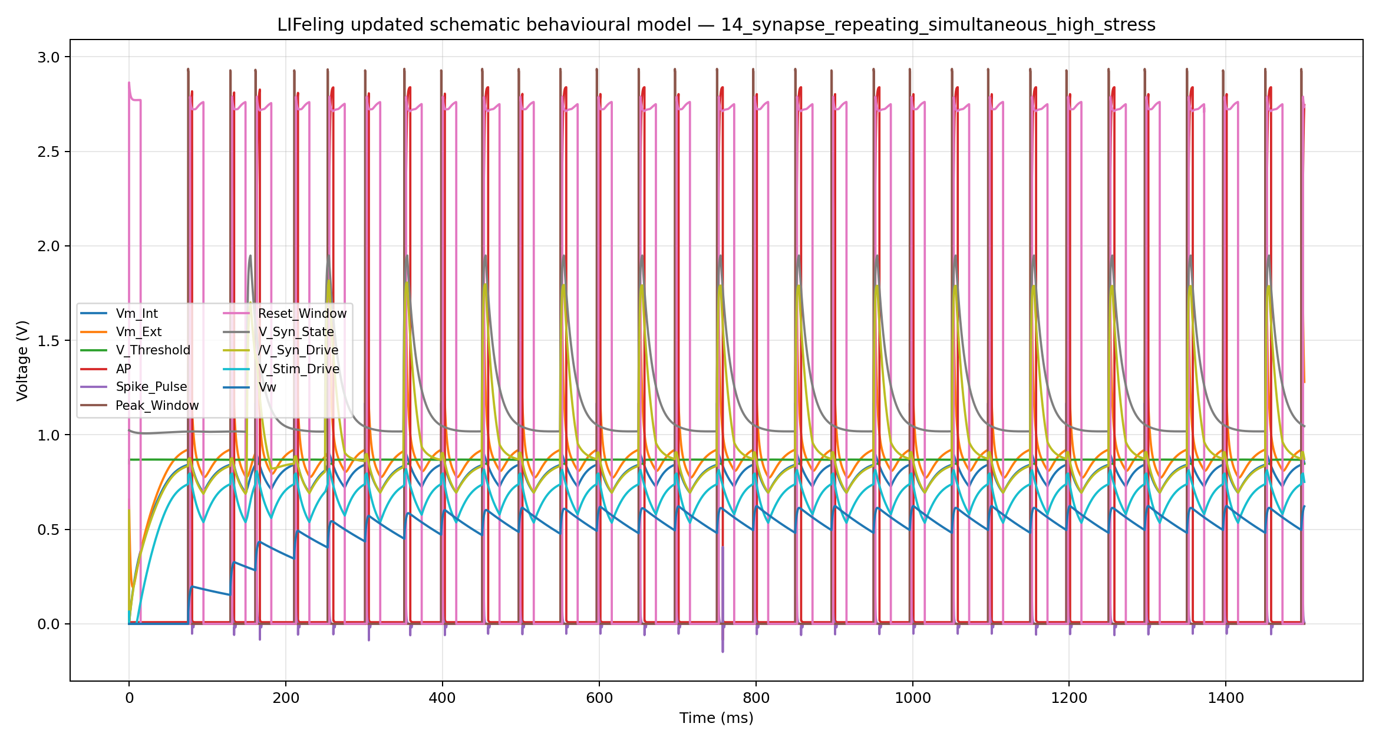
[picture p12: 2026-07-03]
SPICE/LIFeling_pyspice_output/LIFeling_updated_14_synapse_repeating_simultaneous_high_stress_rv0p70_0p50_0p80_0p30_vb3_t1p5_syn1234_4b4a4192.png

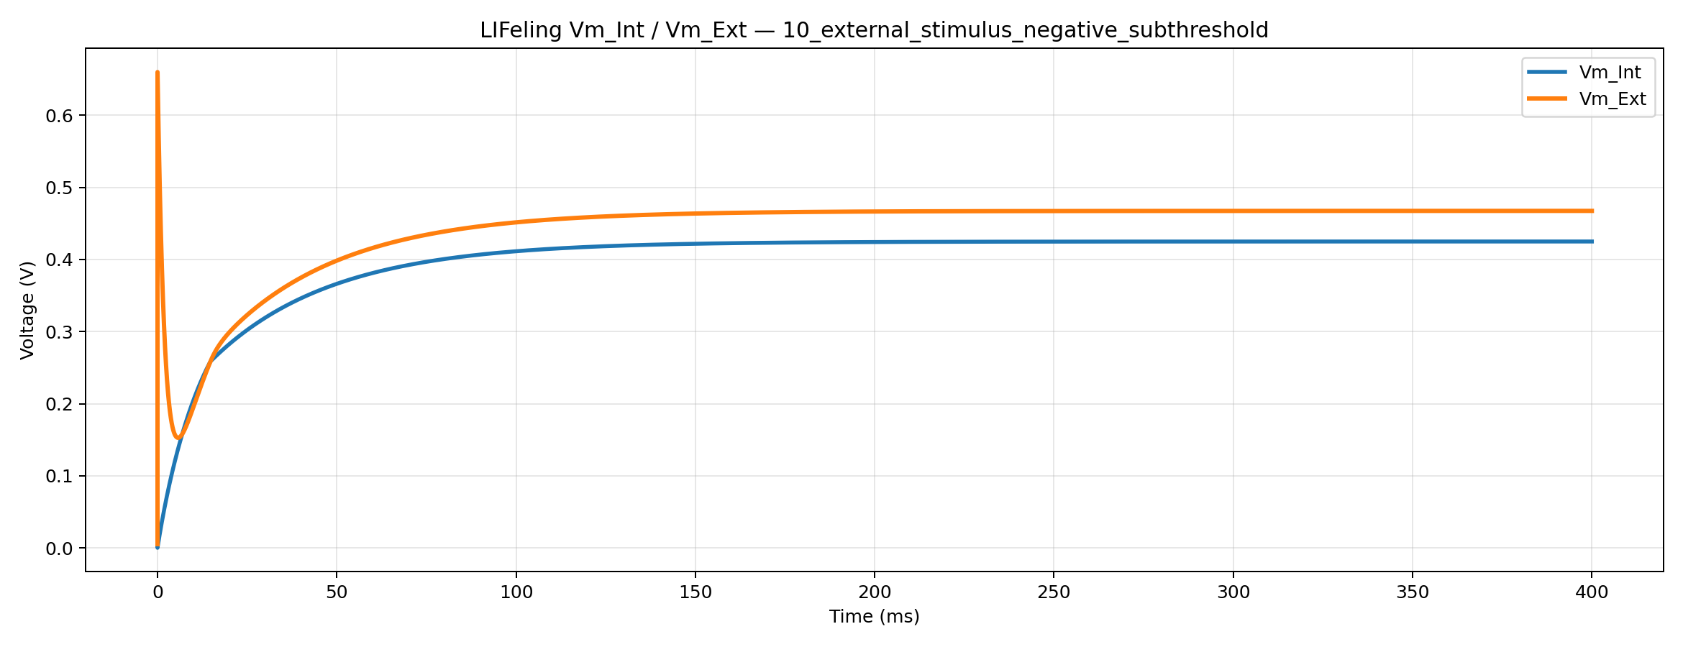
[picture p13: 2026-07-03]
SPICE/LIFeling_pyspice_output/LIFeling_updated_10_external_stimulus_negative_subthreshold_rv0p35_0p50_0p80_0p30_vb3_t400m_b27fb7e2_vmint_vmext.png

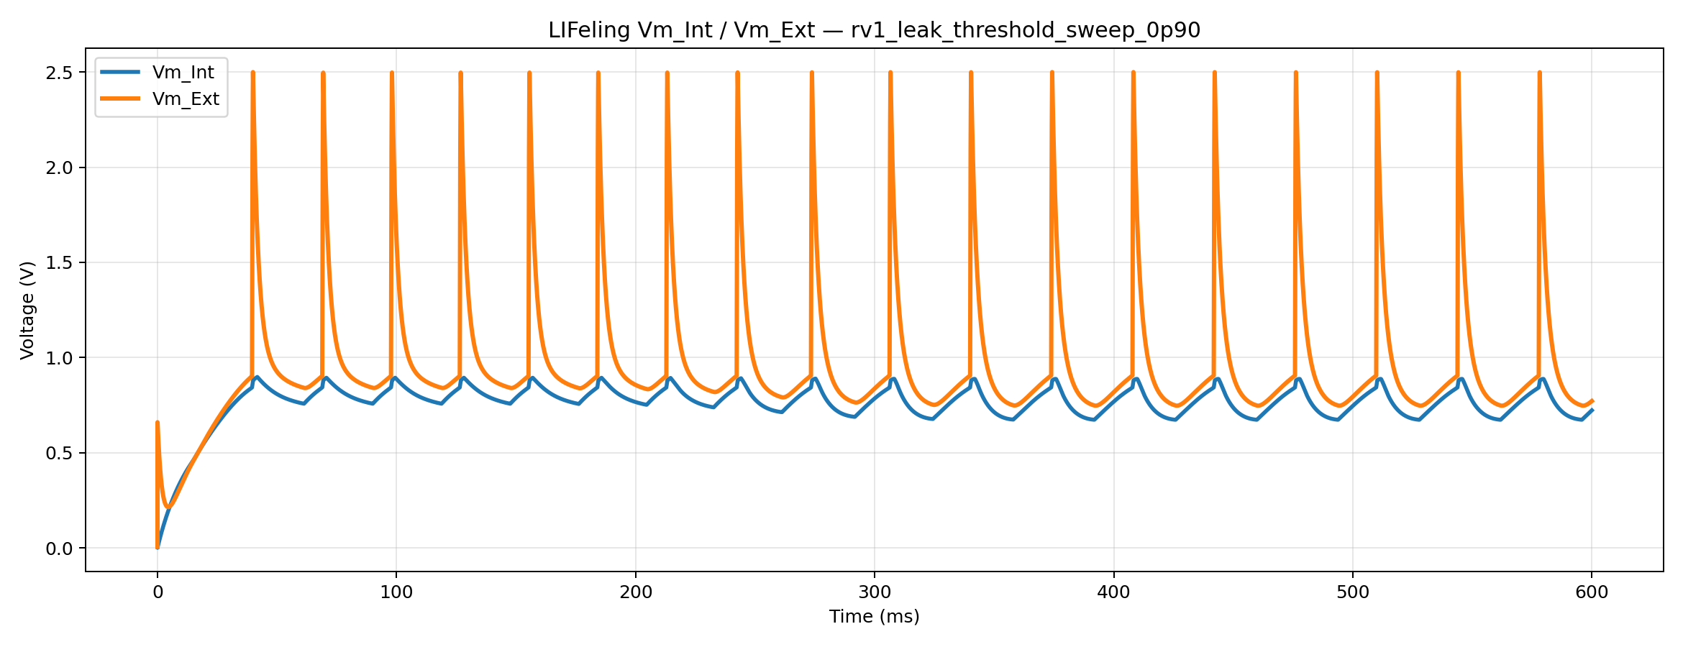
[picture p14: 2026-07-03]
SPICE/LIFeling_pyspice_output/LIFeling_updated_rv1_leak_threshold_sweep_0p90_rv0p90_0p50_0p80_0p30_vb3_t600m_71ecc1f5_vmint_vmext.png

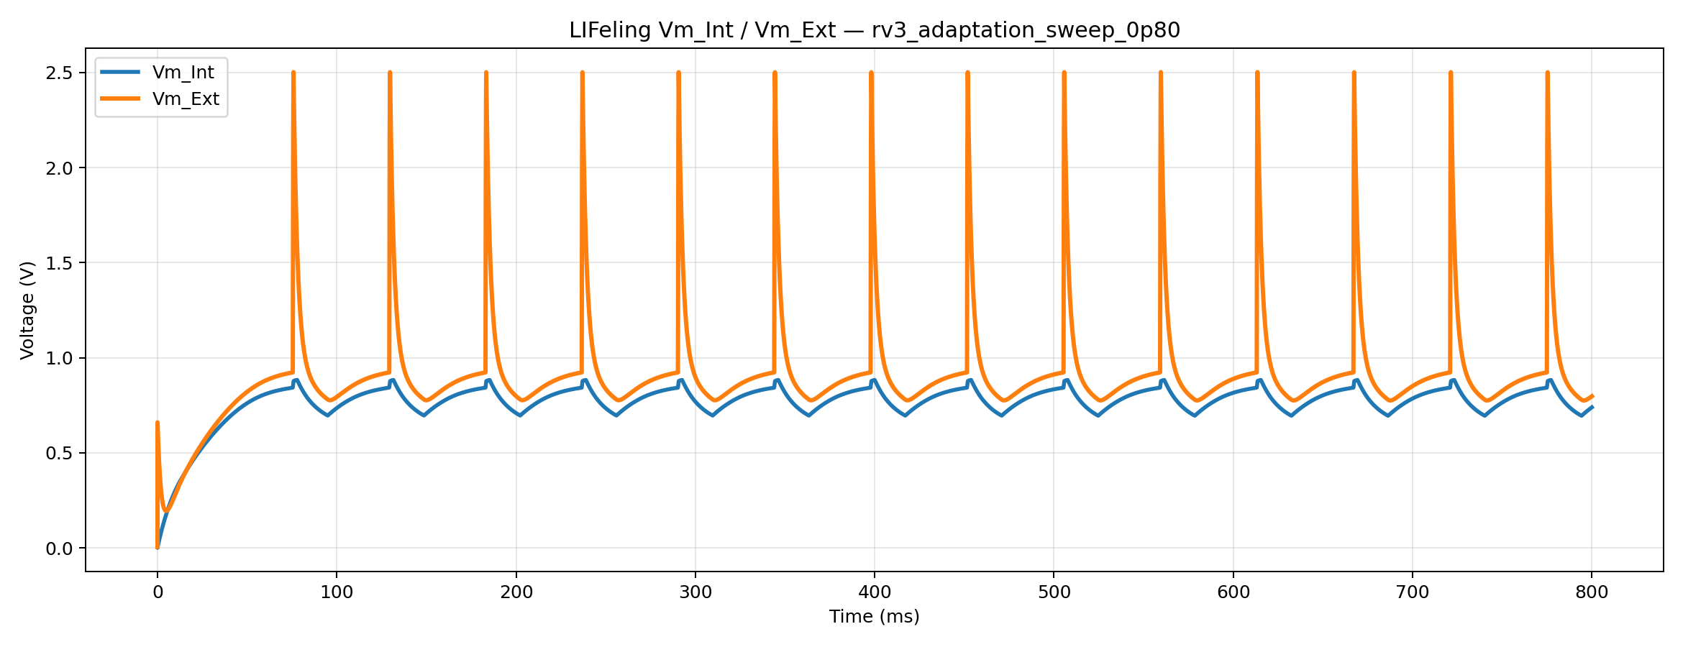
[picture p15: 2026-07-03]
SPICE/LIFeling_pyspice_output/LIFeling_updated_rv3_adaptation_sweep_0p80_rv0p70_0p50_0p80_0p30_vb3_t800m_86bd8272_vmint_vmext.png

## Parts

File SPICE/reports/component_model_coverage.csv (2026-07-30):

reference | value | category | model_note | model_confidence | simulation_status | functional_block
BT1 | type="R" model="Battery_Cell" lib="" | datasheet-derived electrical model | CR2032 fixed-source or dynamic equivalent; exact cell manufacturer unresolved | medium | CR2032 fixed-source or dynamic equivalent; exact cell manufacturer unresolved | power and precision references
C1 | 10uF | ordinary passive instantiated directly | capacitor with ESR, leakage, ESL and optional DC-bias derating | medium | capacitor with ESR, leakage, ESL and optional DC-bias derating | power and precision references
C2 | 10uF | ordinary passive instantiated directly | capacitor with ESR, leakage, ESL and optional DC-bias derating | medium | capacitor with ESR, leakage, ESL and optional DC-bias derating | local decoupling
C3 | 100nF | ordinary passive instantiated directly | capacitor with ESR, leakage, ESL and optional DC-bias derating | medium | capacitor with ESR, leakage, ESL and optional DC-bias derating | local decoupling
C4 | 100nF | ordinary passive instantiated directly | capacitor with ESR, leakage, ESL and optional DC-bias derating | medium | capacitor with ESR, leakage, ESL and optional DC-bias derating | local decoupling
C5 | 100nF | ordinary passive instantiated directly | capacitor with ESR, leakage, ESL and optional DC-bias derating | medium | capacitor with ESR, leakage, ESL and optional DC-bias derating | local decoupling
C6 | 100nF | ordinary passive instantiated directly | capacitor with ESR, leakage, ESL and optional DC-bias derating | medium | capacitor with ESR, leakage, ESL and optional DC-bias derating | local decoupling
C7 | 100nF | ordinary passive instantiated directly | capacitor with ESR, leakage, ESL and optional DC-bias derating | medium | capacitor with ESR, leakage, ESL and optional DC-bias derating | local decoupling
C8 | 100nF | ordinary passive instantiated directly | capacitor with ESR, leakage, ESL and optional DC-bias derating | medium | capacitor with ESR, leakage, ESL and optional DC-bias derating | local decoupling
C9 | 10uF | ordinary passive instantiated directly | capacitor with ESR, leakage, ESL and optional DC-bias derating | medium | capacitor with ESR, leakage, ESL and optional DC-bias derating | local decoupling
C10 | 22uF | ordinary passive instantiated directly | capacitor with ESR, leakage, ESL and optional DC-bias derating | medium | capacitor with ESR, leakage, ESL and optional DC-bias derating | miscellaneous schematic support
C11 | 1uF | ordinary passive instantiated directly | capacitor with ESR, leakage, ESL and optional DC-bias derating | medium | capacitor with ESR, leakage, ESL and optional DC-bias derating | power and precision references
C12 | 100nF | ordinary passive instantiated directly | capacitor with ESR, leakage, ESL and optional DC-bias derating | medium | capacitor with ESR, leakage, ESL and optional DC-bias derating | power and precision references
C13 | 100pF | ordinary passive instantiated directly | capacitor with ESR, leakage, ESL and optional DC-bias derating | medium | capacitor with ESR, leakage, ESL and optional DC-bias derating | external membrane display/output
C14 | 100nF | ordinary passive instantiated directly | capacitor with ESR, leakage, ESL and optional DC-bias derating | medium | capacitor with ESR, leakage, ESL and optional DC-bias derating | power and precision references
C15 | 100nF | ordinary passive instantiated directly | capacitor with ESR, leakage, ESL and optional DC-bias derating | medium | capacitor with ESR, leakage, ESL and optional DC-bias derating | power and precision references
C16 | 22nF | ordinary passive instantiated directly | capacitor with ESR, leakage, ESL and optional DC-bias derating | medium | capacitor with ESR, leakage, ESL and optional DC-bias derating | external membrane display/output
C17 | 100nF | ordinary passive instantiated directly | capacitor with ESR, leakage, ESL and optional DC-bias derating | medium | capacitor with ESR, leakage, ESL and optional DC-bias derating | local decoupling
C18 | 470nF | ordinary passive instantiated directly | capacitor with ESR, leakage, ESL and optional DC-bias derating | medium | capacitor with ESR, leakage, ESL and optional DC-bias derating | membrane capacitance selector
C19 | 100nF | ordinary passive instantiated directly | capacitor with ESR, leakage, ESL and optional DC-bias derating | medium | capacitor with ESR, leakage, ESL and optional DC-bias derating | local decoupling
C20 | 1uF | ordinary passive instantiated directly | capacitor with ESR, leakage, ESL and optional DC-bias derating | medium | capacitor with ESR, leakage, ESL and optional DC-bias derating | membrane capacitance selector
C21 | 100nF | ordinary passive instantiated directly | capacitor with ESR, leakage, ESL and optional DC-bias derating | medium | capacitor with ESR, leakage, ESL and optional DC-bias derating | local decoupling
C22 | 2.2uF | ordinary passive instantiated directly | capacitor with ESR, leakage, ESL and optional DC-bias derating | medium | capacitor with ESR, leakage, ESL and optional DC-bias derating | membrane capacitance selector
C23 | 100nF | ordinary passive instantiated directly | capacitor with ESR, leakage, ESL and optional DC-bias derating | medium | capacitor with ESR, leakage, ESL and optional DC-bias derating | local decoupling
C24 | 4.7uF | ordinary passive instantiated directly | capacitor with ESR, leakage, ESL and optional DC-bias derating | medium | capacitor with ESR, leakage, ESL and optional DC-bias derating | membrane capacitance selector
C25 | 100nF | ordinary passive instantiated directly | capacitor with ESR, leakage, ESL and optional DC-bias derating | medium | capacitor with ESR, leakage, ESL and optional DC-bias derating | local decoupling
C26 | 10uF | ordinary passive instantiated directly | capacitor with ESR, leakage, ESL and optional DC-bias derating | medium | capacitor with ESR, leakage, ESL and optional DC-bias derating | membrane capacitance selector
C27 | 100nF | ordinary passive instantiated directly | capacitor with ESR, leakage, ESL and optional DC-bias derating | medium | capacitor with ESR, leakage, ESL and optional DC-bias derating | local decoupling
C28 | 100pF | ordinary passive instantiated directly | capacitor with ESR, leakage, ESL and optional DC-bias derating | medium | capacitor with ESR, leakage, ESL and optional DC-bias derating | membrane leak and integration
C29 | 1uF | ordinary passive instantiated directly | capacitor with ESR, leakage, ESL and optional DC-bias derating | medium | capacitor with ESR, leakage, ESL and optional DC-bias derating | adaptation
C30 | 10uF | ordinary passive instantiated directly | capacitor with ESR, leakage, ESL and optional DC-bias derating | medium | capacitor with ESR, leakage, ESL and optional DC-bias derating | adaptation
C31 | 10nF | ordinary passive instantiated directly | capacitor with ESR, leakage, ESL and optional DC-bias derating | medium | capacitor with ESR, leakage, ESL and optional DC-bias derating | threshold, AP, peak, reset and spike output
C32 | 100nF | ordinary passive instantiated directly | capacitor with ESR, leakage, ESL and optional DC-bias derating | medium | capacitor with ESR, leakage, ESL and optional DC-bias derating | local decoupling
C33 | 1uF | ordinary passive instantiated directly | capacitor with ESR, leakage, ESL and optional DC-bias derating | medium | capacitor with ESR, leakage, ESL and optional DC-bias derating | miscellaneous schematic support
C34 | 100nF | ordinary passive instantiated directly | capacitor with ESR, leakage, ESL and optional DC-bias derating | medium | capacitor with ESR, leakage, ESL and optional DC-bias derating | local decoupling
C35 | 100nF | ordinary passive instantiated directly | capacitor with ESR, leakage, ESL and optional DC-bias derating | medium | capacitor with ESR, leakage, ESL and optional DC-bias derating | local decoupling
C36 | 100nF | ordinary passive instantiated directly | capacitor with ESR, leakage, ESL and optional DC-bias derating | medium | capacitor with ESR, leakage, ESL and optional DC-bias derating | local decoupling
C37 | 100nF | ordinary passive instantiated directly | capacitor with ESR, leakage, ESL and optional DC-bias derating | medium | capacitor with ESR, leakage, ESL and optional DC-bias derating | local decoupling
C38 | 220nF | ordinary passive instantiated directly | capacitor with ESR, leakage, ESL and optional DC-bias derating | medium | capacitor with ESR, leakage, ESL and optional DC-bias derating | signed synapses
C39 | 100pF | ordinary passive instantiated directly | capacitor with ESR, leakage, ESL and optional DC-bias derating | medium | capacitor with ESR, leakage, ESL and optional DC-bias derating | external stimulus
C40 | 100nF | ordinary passive instantiated directly | capacitor with ESR, leakage, ESL and optional DC-bias derating | medium | capacitor with ESR, leakage, ESL and optional DC-bias derating | local decoupling
C41 | 100nF | ordinary passive instantiated directly | capacitor with ESR, leakage, ESL and optional DC-bias derating | medium | capacitor with ESR, leakage, ESL and optional DC-bias derating | local decoupling
C42 | 100nF | ordinary passive instantiated directly | capacitor with ESR, leakage, ESL and optional DC-bias derating | medium | capacitor with ESR, leakage, ESL and optional DC-bias derating | local decoupling
C43 | 100nF | ordinary passive instantiated directly | capacitor with ESR, leakage, ESL and optional DC-bias derating | medium | capacitor with ESR, leakage, ESL and optional DC-bias derating | local decoupling
D1 | TPD1E05U06DPYT | datasheet-derived electrical model | LIF_TPD1E05U06 | medium | portable fallback | external membrane display/output
D2 | BAT54WS L9 | datasheet-derived electrical model | LIF_BAT54WS | medium | portable fallback | membrane leak and integration
D3 | BAT54WS L9 | datasheet-derived electrical model | LIF_BAT54WS | medium | portable fallback | membrane leak and integration
D4 | 1N4148WS | datasheet-derived electrical model | 1N4148 | medium | installed comparison model; portable fallback selected | adaptation
D5 | 1N4148WS | datasheet-derived electrical model | 1N4148 | medium | installed comparison model; portable fallback selected | adaptation
D6 | RB521S30T1G | datasheet-derived electrical model | LIF_RB521S30 | medium | portable fallback | adaptation
D7 | 1N4148WS | datasheet-derived electrical model | 1N4148 | medium | installed comparison model; portable fallback selected | adaptation
D8 | RB521S30T1G | datasheet-derived electrical model | LIF_RB521S30 | medium | portable fallback | threshold, AP, peak, reset and spike output
D9 | 19-237/R6GHBHC-A01/2T | datasheet-derived electrical model | three colour-specific LED model cards | medium | portable fallback | miscellaneous schematic support
D10 | BAT54WS L9 | datasheet-derived electrical model | LIF_BAT54WS | medium | portable fallback | miscellaneous schematic support
D11 | BAT54WS L9 | datasheet-derived electrical model | LIF_BAT54WS | medium | portable fallback | miscellaneous schematic support
D12 | BAT54WS L9 | datasheet-derived electrical model | LIF_BAT54WS | medium | portable fallback | miscellaneous schematic support
D13 | BAT54WS L9 | datasheet-derived electrical model | LIF_BAT54WS | medium | portable fallback | miscellaneous schematic support
D14 | BAT54WS L9 | datasheet-derived electrical model | LIF_BAT54WS | medium | portable fallback | miscellaneous schematic support
D15 | BAT54WS L9 | datasheet-derived electrical model | LIF_BAT54WS | medium | portable fallback | miscellaneous schematic support
D16 | BAT54WS L9 | datasheet-derived electrical model | LIF_BAT54WS | medium | portable fallback | miscellaneous schematic support
D17 | BAT54WS L9 | datasheet-derived electrical model | LIF_BAT54WS | medium | portable fallback | miscellaneous schematic support
D18 | TPD1E05U06DPYT | datasheet-derived electrical model | LIF_TPD1E05U06 | medium | portable fallback | threshold, AP, peak, reset and spike output
D19 | TPD1E05U06DPYT | datasheet-derived electrical model | LIF_TPD1E05U06 | medium | portable fallback | external stimulus
D20 | RB521S30T1G | datasheet-derived electrical model | LIF_RB521S30 | medium | portable fallback | threshold, AP, peak, reset and spike output
D21 | BAT54WS L9 | datasheet-derived electrical model | LIF_BAT54WS | medium | portable fallback | external membrane display/output
D22 | BAT54WS L9 | datasheet-derived electrical model | LIF_BAT54WS | medium | portable fallback | external membrane display/output
H1 | MountingHole | mechanical-only | mounting hole; deliberately omitted electrically | high | mounting hole; deliberately omitted electrically | local decoupling
H2 | MountingHole | mechanical-only | mounting hole; deliberately omitted electrically | high | mounting hole; deliberately omitted electrically | local decoupling
H3 | MountingHole | mechanical-only | mounting hole; deliberately omitted electrically | high | mounting hole; deliberately omitted electrically | local decoupling
H4 | MountingHole | mechanical-only | mounting hole; deliberately omitted electrically | high | mounting hole; deliberately omitted electrically | local decoupling
H5 | MountingHole | mechanical-only | mounting hole; deliberately omitted electrically | high | mounting hole; deliberately omitted electrically | local decoupling
H6 | MountingHole | mechanical-only | mounting hole; deliberately omitted electrically | high | mounting hole; deliberately omitted electrically | local decoupling
J1 | Stim_Ext | connector or external terminal | physical pins retained as external nets | high | physical pins retained as external nets | external stimulus
J2 | Axon_Output | connector or external terminal | physical pins retained as external nets | high | physical pins retained as external nets | threshold, AP, peak, reset and spike output
J3 | Syn1_Input | connector or external terminal | physical pins retained as external nets | high | physical pins retained as external nets | signed synapses
J4 | Syn2_Input | connector or external terminal | physical pins retained as external nets | high | physical pins retained as external nets | signed synapses
J5 | Syn3_Input | connector or external terminal | physical pins retained as external nets | high | physical pins retained as external nets | signed synapses
J6 | Syn4_Input | connector or external terminal | physical pins retained as external nets | high | physical pins retained as external nets | signed synapses
L1 | 2.2uH | datasheet-derived electrical model | inductance plus DCR/parasitic capacitance; saturation checked numerically | medium | inductance plus DCR/parasitic capacitance; saturation checked numerically | power and precision references
Q1 | BSS138 | datasheet-derived electrical model | LIF_BSS138 | medium | portable fallback | threshold, AP, peak, reset and spike output
Q2 | MMBT3904 | datasheet-derived electrical model | DI_MMBT3904 | medium | installed comparison model; portable fallback selected | miscellaneous schematic support
Q3 | BSS138 | datasheet-derived electrical model | LIF_BSS138 | medium | portable fallback | threshold, AP, peak, reset and spike output
Q4 | BSS138 | datasheet-derived electrical model | LIF_BSS138 | medium | portable fallback | threshold, AP, peak, reset and spike output
Q5 | BSS138 | datasheet-derived electrical model | LIF_BSS138 | medium | portable fallback | miscellaneous schematic support
Q6 | BSS138 | datasheet-derived electrical model | LIF_BSS138 | medium | portable fallback | threshold, AP, peak, reset and spike output
Q7 | BSS138 | datasheet-derived electrical model | LIF_BSS138 | medium | portable fallback | threshold, AP, peak, reset and spike output
Q8 | MMBT3904 | datasheet-derived electrical model | DI_MMBT3904 | medium | installed comparison model; portable fallback selected | miscellaneous schematic support
R1 | 10Ω | ordinary passive instantiated directly | direct resistor with tolerance support | high | direct resistor with tolerance support | power and precision references
R2 | 220Ω | ordinary passive instantiated directly | direct resistor with tolerance support | high | direct resistor with tolerance support | external membrane display/output
R3 | 10kΩ | ordinary passive instantiated directly | direct resistor with tolerance support | high | direct resistor with tolerance support | external membrane display/output
R4 | 100kΩ | ordinary passive instantiated directly | direct resistor with tolerance support | high | direct resistor with tolerance support | external membrane display/output
R5 | 220kΩ | ordinary passive instantiated directly | direct resistor with tolerance support | high | direct resistor with tolerance support | power and precision references
R6 | 220kΩ | ordinary passive instantiated directly | direct resistor with tolerance support | high | direct resistor with tolerance support | miscellaneous schematic support
R7 | 20kΩ | ordinary passive instantiated directly | direct resistor with tolerance support | high | direct resistor with tolerance support | power and precision references
R8 | 100kΩ | ordinary passive instantiated directly | direct resistor with tolerance support | high | direct resistor with tolerance support | membrane leak and integration
R9 | 100kΩ | ordinary passive instantiated directly | direct resistor with tolerance support | high | direct resistor with tolerance support | power and precision references
R10 | 56kΩ | ordinary passive instantiated directly | direct resistor with tolerance support | high | direct resistor with tolerance support | miscellaneous schematic support
R11 | 100kΩ | ordinary passive instantiated directly | direct resistor with tolerance support | high | direct resistor with tolerance support | miscellaneous schematic support
R12 | 1MΩ | ordinary passive instantiated directly | direct resistor with tolerance support | high | direct resistor with tolerance support | miscellaneous schematic support
R13 | 220kΩ | ordinary passive instantiated directly | direct resistor with tolerance support | high | direct resistor with tolerance support | miscellaneous schematic support
R14 | 220kΩ | ordinary passive instantiated directly | direct resistor with tolerance support | high | direct resistor with tolerance support | miscellaneous schematic support
R15 | 100kΩ | ordinary passive instantiated directly | direct resistor with tolerance support | high | direct resistor with tolerance support | membrane leak and integration
R16 | 10kΩ | ordinary passive instantiated directly | direct resistor with tolerance support | high | direct resistor with tolerance support | miscellaneous schematic support
R17 | 100kΩ | ordinary passive instantiated directly | direct resistor with tolerance support | high | direct resistor with tolerance support | membrane capacitance selector
R18 | 100kΩ | ordinary passive instantiated directly | direct resistor with tolerance support | high | direct resistor with tolerance support | membrane capacitance selector
R19 | 100kΩ | ordinary passive instantiated directly | direct resistor with tolerance support | high | direct resistor with tolerance support | membrane capacitance selector
R20 | 100kΩ | ordinary passive instantiated directly | direct resistor with tolerance support | high | direct resistor with tolerance support | membrane capacitance selector
R21 | 100kΩ | ordinary passive instantiated directly | direct resistor with tolerance support | high | direct resistor with tolerance support | membrane capacitance selector
R22 | 100kΩ | ordinary passive instantiated directly | direct resistor with tolerance support | high | direct resistor with tolerance support | membrane capacitance selector
R23 | 1MΩ | ordinary passive instantiated directly | direct resistor with tolerance support | high | direct resistor with tolerance support | membrane capacitance selector
R24 | 100kΩ | ordinary passive instantiated directly | direct resistor with tolerance support | high | direct resistor with tolerance support | membrane capacitance selector
R25 | 1MΩ | ordinary passive instantiated directly | direct resistor with tolerance support | high | direct resistor with tolerance support | membrane capacitance selector
R26 | 1MΩ | ordinary passive instantiated directly | direct resistor with tolerance support | high | direct resistor with tolerance support | membrane capacitance selector
R27 | 100kΩ | ordinary passive instantiated directly | direct resistor with tolerance support | high | direct resistor with tolerance support | membrane capacitance selector
R28 | 1MΩ | ordinary passive instantiated directly | direct resistor with tolerance support | high | direct resistor with tolerance support | membrane capacitance selector
R29 | 1MΩ | ordinary passive instantiated directly | direct resistor with tolerance support | high | direct resistor with tolerance support | membrane capacitance selector
R30 | 100kΩ | ordinary passive instantiated directly | direct resistor with tolerance support | high | direct resistor with tolerance support | membrane capacitance selector
R31 | 1MΩ | ordinary passive instantiated directly | direct resistor with tolerance support | high | direct resistor with tolerance support | membrane capacitance selector
R32 | 1MΩ | ordinary passive instantiated directly | direct resistor with tolerance support | high | direct resistor with tolerance support | membrane capacitance selector
R33 | 100kΩ | ordinary passive instantiated directly | direct resistor with tolerance support | high | direct resistor with tolerance support | membrane capacitance selector
R34 | 1MΩ | ordinary passive instantiated directly | direct resistor with tolerance support | high | direct resistor with tolerance support | membrane capacitance selector
R35 | 1kΩ | ordinary passive instantiated directly | direct resistor with tolerance support | high | direct resistor with tolerance support | membrane leak and integration
R36 | 2.2MΩ | ordinary passive instantiated directly | direct resistor with tolerance support | high | direct resistor with tolerance support | threshold, AP, peak, reset and spike output
R37 | 10kΩ | ordinary passive instantiated directly | direct resistor with tolerance support | high | direct resistor with tolerance support | threshold, AP, peak, reset and spike output
R38 | 100kΩ | ordinary passive instantiated directly | direct resistor with tolerance support | high | direct resistor with tolerance support | threshold, AP, peak, reset and spike output
R39 | 22kΩ | ordinary passive instantiated directly | direct resistor with tolerance support | high | direct resistor with tolerance support | adaptation
R40 | 100Ω | ordinary passive instantiated directly | direct resistor with tolerance support | high | direct resistor with tolerance support | miscellaneous schematic support
R41 | 200kΩ | ordinary passive instantiated directly | direct resistor with tolerance support | high | direct resistor with tolerance support | miscellaneous schematic support
R42 | 100kΩ | ordinary passive instantiated directly | direct resistor with tolerance support | high | direct resistor with tolerance support | membrane leak and integration
R43 | 100kΩ | ordinary passive instantiated directly | direct resistor with tolerance support | high | direct resistor with tolerance support | membrane leak and integration
R44 | 200kΩ | ordinary passive instantiated directly | direct resistor with tolerance support | high | direct resistor with tolerance support | adaptation
R45 | 330kΩ | ordinary passive instantiated directly | direct resistor with tolerance support | high | direct resistor with tolerance support | adaptation
R46 | 10kΩ | ordinary passive instantiated directly | direct resistor with tolerance support | high | direct resistor with tolerance support | membrane leak and integration
R47 | 22kΩ | ordinary passive instantiated directly | direct resistor with tolerance support | high | direct resistor with tolerance support | adaptation
R48 | 100kΩ | ordinary passive instantiated directly | direct resistor with tolerance support | high | direct resistor with tolerance support | miscellaneous schematic support
R49 | 100kΩ | ordinary passive instantiated directly | direct resistor with tolerance support | high | direct resistor with tolerance support | miscellaneous schematic support
R50 | 1MΩ | ordinary passive instantiated directly | direct resistor with tolerance support | high | direct resistor with tolerance support | threshold, AP, peak, reset and spike output
R51 | 100kΩ | ordinary passive instantiated directly | direct resistor with tolerance support | high | direct resistor with tolerance support | threshold, AP, peak, reset and spike output
R52 | 10kΩ | ordinary passive instantiated directly | direct resistor with tolerance support | high | direct resistor with tolerance support | miscellaneous schematic support
R53 | 22kΩ | ordinary passive instantiated directly | direct resistor with tolerance support | high | direct resistor with tolerance support | miscellaneous schematic support
R54 | 100Ω | ordinary passive instantiated directly | direct resistor with tolerance support | high | direct resistor with tolerance support | miscellaneous schematic support
R55 | 100kΩ | ordinary passive instantiated directly | direct resistor with tolerance support | high | direct resistor with tolerance support | threshold, AP, peak, reset and spike output
R56 | 270kΩ | ordinary passive instantiated directly | direct resistor with tolerance support | high | direct resistor with tolerance support | miscellaneous schematic support
R57 | 1MΩ | ordinary passive instantiated directly | direct resistor with tolerance support | high | direct resistor with tolerance support | threshold, AP, peak, reset and spike output
R58 | 220kΩ | ordinary passive instantiated directly | direct resistor with tolerance support | high | direct resistor with tolerance support | miscellaneous schematic support
R59 | 100kΩ | ordinary passive instantiated directly | direct resistor with tolerance support | high | direct resistor with tolerance support | miscellaneous schematic support
R60 | 10kΩ | ordinary passive instantiated directly | direct resistor with tolerance support | high | direct resistor with tolerance support | membrane leak and integration
R61 | 2kΩ | ordinary passive instantiated directly | direct resistor with tolerance support | high | direct resistor with tolerance support | miscellaneous schematic support
R62 | 2kΩ | ordinary passive instantiated directly | direct resistor with tolerance support | high | direct resistor with tolerance support | miscellaneous schematic support
R63 | 2kΩ | ordinary passive instantiated directly | direct resistor with tolerance support | high | direct resistor with tolerance support | miscellaneous schematic support
R64 | 10kΩ | ordinary passive instantiated directly | direct resistor with tolerance support | high | direct resistor with tolerance support | membrane leak and integration
R65 | 100kΩ | ordinary passive instantiated directly | direct resistor with tolerance support | high | direct resistor with tolerance support | miscellaneous schematic support
R66 | 22kΩ | ordinary passive instantiated directly | direct resistor with tolerance support | high | direct resistor with tolerance support | signed synapses
R67 | 1kΩ | ordinary passive instantiated directly | direct resistor with tolerance support | high | direct resistor with tolerance support | miscellaneous schematic support
R68 | 100kΩ | ordinary passive instantiated directly | direct resistor with tolerance support | high | direct resistor with tolerance support | miscellaneous schematic support
R69 | 22kΩ | ordinary passive instantiated directly | direct resistor with tolerance support | high | direct resistor with tolerance support | signed synapses
R70 | 22kΩ | ordinary passive instantiated directly | direct resistor with tolerance support | high | direct resistor with tolerance support | signed synapses
R71 | 1kΩ | ordinary passive instantiated directly | direct resistor with tolerance support | high | direct resistor with tolerance support | miscellaneous schematic support
R72 | 100kΩ | ordinary passive instantiated directly | direct resistor with tolerance support | high | direct resistor with tolerance support | miscellaneous schematic support
R73 | 22kΩ | ordinary passive instantiated directly | direct resistor with tolerance support | high | direct resistor with tolerance support | signed synapses
R74 | 22kΩ | ordinary passive instantiated directly | direct resistor with tolerance support | high | direct resistor with tolerance support | signed synapses
R75 | 1kΩ | ordinary passive instantiated directly | direct resistor with tolerance support | high | direct resistor with tolerance support | miscellaneous schematic support
R76 | 100kΩ | ordinary passive instantiated directly | direct resistor with tolerance support | high | direct resistor with tolerance support | miscellaneous schematic support
R77 | 22kΩ | ordinary passive instantiated directly | direct resistor with tolerance support | high | direct resistor with tolerance support | signed synapses
R78 | 22kΩ | ordinary passive instantiated directly | direct resistor with tolerance support | high | direct resistor with tolerance support | signed synapses
R79 | 1kΩ | ordinary passive instantiated directly | direct resistor with tolerance support | high | direct resistor with tolerance support | miscellaneous schematic support
R80 | 100kΩ | ordinary passive instantiated directly | direct resistor with tolerance support | high | direct resistor with tolerance support | miscellaneous schematic support
R81 | 22kΩ | ordinary passive instantiated directly | direct resistor with tolerance support | high | direct resistor with tolerance support | signed synapses
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

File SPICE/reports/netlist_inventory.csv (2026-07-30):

reference | value | footprint | manufacturer | manufacturer_part | supplier_number | physical_pin | pin_function | pin_type | connected_net | functional_block | model_category | model_file | model_subcircuit | model_terminal_order | model_confidence | simulation_status
BT1 | type="R" model="Battery_Cell" lib="" | Maxime:BAT-TH_CR2032-BS-6-1 |  |  | C70377 | 1 | +_1 | passive | +BATT | power and precision references | datasheet-derived electrical model |  |  |  | medium | CR2032 fixed-source or dynamic equivalent; exact cell manufacturer unresolved
BT1 | type="R" model="Battery_Cell" lib="" | Maxime:BAT-TH_CR2032-BS-6-1 |  |  | C70377 | 2 | -_2 | passive | GNDREF | power and precision references | datasheet-derived electrical model |  |  |  | medium | CR2032 fixed-source or dynamic equivalent; exact cell manufacturer unresolved
C1 | 10uF | JLCPCB:C_0805 | SAMSUNG(三星) | CL05A106MP5NUNC | C15850 | 1 | 1_1 | passive | +BATT | power and precision references | ordinary passive instantiated directly |  |  |  | medium | capacitor with ESR, leakage, ESL and optional DC-bias derating
C1 | 10uF | JLCPCB:C_0805 | SAMSUNG(三星) | CL05A106MP5NUNC | C15850 | 2 | 2_2 | passive | GNDREF | power and precision references | ordinary passive instantiated directly |  |  |  | medium | capacitor with ESR, leakage, ESL and optional DC-bias derating
C2 | 10uF | JLCPCB:C_0805 | SAMSUNG(三星) | CL05A106MP5NUNC | C15850 | 1 | 1_1 | passive | VDD | local decoupling | ordinary passive instantiated directly |  |  |  | medium | capacitor with ESR, leakage, ESL and optional DC-bias derating
C2 | 10uF | JLCPCB:C_0805 | SAMSUNG(三星) | CL05A106MP5NUNC | C15850 | 2 | 2_2 | passive | GNDREF | local decoupling | ordinary passive instantiated directly |  |  |  | medium | capacitor with ESR, leakage, ESL and optional DC-bias derating
C3 | 100nF | JLCPCB:C_0402 | SAMSUNG(三星) | CL05B104KO5NNNC | C1525 | 1 | 1_1 | passive | GNDREF | local decoupling | ordinary passive instantiated directly |  |  |  | medium | capacitor with ESR, leakage, ESL and optional DC-bias derating
C3 | 100nF | JLCPCB:C_0402 | SAMSUNG(三星) | CL05B104KO5NNNC | C1525 | 2 | 2_2 | passive | VDD | local decoupling | ordinary passive instantiated directly |  |  |  | medium | capacitor with ESR, leakage, ESL and optional DC-bias derating
C4 | 100nF | JLCPCB:C_0402 | SAMSUNG(三星) | CL05B104KO5NNNC | C1525 | 1 | 1_1 | passive | GNDREF | local decoupling | ordinary passive instantiated directly |  |  |  | medium | capacitor with ESR, leakage, ESL and optional DC-bias derating
C4 | 100nF | JLCPCB:C_0402 | SAMSUNG(三星) | CL05B104KO5NNNC | C1525 | 2 | 2_2 | passive | VDD | local decoupling | ordinary passive instantiated directly |  |  |  | medium | capacitor with ESR, leakage, ESL and optional DC-bias derating
C5 | 100nF | JLCPCB:C_0402 | SAMSUNG(三星) | CL05B104KO5NNNC | C1525 | 1 | 1_1 | passive | GNDREF | local decoupling | ordinary passive instantiated directly |  |  |  | medium | capacitor with ESR, leakage, ESL and optional DC-bias derating
C5 | 100nF | JLCPCB:C_0402 | SAMSUNG(三星) | CL05B104KO5NNNC | C1525 | 2 | 2_2 | passive | VDD | local decoupling | ordinary passive instantiated directly |  |  |  | medium | capacitor with ESR, leakage, ESL and optional DC-bias derating
C6 | 100nF | JLCPCB:C_0402 | SAMSUNG(三星) | CL05B104KO5NNNC | C1525 | 1 | 1_1 | passive | GNDREF | local decoupling | ordinary passive instantiated directly |  |  |  | medium | capacitor with ESR, leakage, ESL and optional DC-bias derating
C6 | 100nF | JLCPCB:C_0402 | SAMSUNG(三星) | CL05B104KO5NNNC | C1525 | 2 | 2_2 | passive | VDD | local decoupling | ordinary passive instantiated directly |  |  |  | medium | capacitor with ESR, leakage, ESL and optional DC-bias derating
C7 | 100nF | JLCPCB:C_0402 | SAMSUNG(三星) | CL05B104KO5NNNC | C1525 | 1 | 1_1 | passive | GNDREF | local decoupling | ordinary passive instantiated directly |  |  |  | medium | capacitor with ESR, leakage, ESL and optional DC-bias derating
C7 | 100nF | JLCPCB:C_0402 | SAMSUNG(三星) | CL05B104KO5NNNC | C1525 | 2 | 2_2 | passive | VDD | local decoupling | ordinary passive instantiated directly |  |  |  | medium | capacitor with ESR, leakage, ESL and optional DC-bias derating
C8 | 100nF | JLCPCB:C_0402 | SAMSUNG(三星) | CL05B104KO5NNNC | C1525 | 1 | 1_1 | passive | GNDREF | local decoupling | ordinary passive instantiated directly |  |  |  | medium | capacitor with ESR, leakage, ESL and optional DC-bias derating
C8 | 100nF | JLCPCB:C_0402 | SAMSUNG(三星) | CL05B104KO5NNNC | C1525 | 2 | 2_2 | passive | VDD | local decoupling | ordinary passive instantiated directly |  |  |  | medium | capacitor with ESR, leakage, ESL and optional DC-bias derating
C9 | 10uF | JLCPCB:C_0805 | SAMSUNG(三星) | CL05A106MP5NUNC | C15850 | 1 | 1_1 | passive | VDD | local decoupling | ordinary passive instantiated directly |  |  |  | medium | capacitor with ESR, leakage, ESL and optional DC-bias derating
C9 | 10uF | JLCPCB:C_0805 | SAMSUNG(三星) | CL05A106MP5NUNC | C15850 | 2 | 2_2 | passive | GNDREF | local decoupling | ordinary passive instantiated directly |  |  |  | medium | capacitor with ESR, leakage, ESL and optional DC-bias derating
C10 | 22uF | JLCPCB:C_0805 | SAMSUNG(三星) | CL21A226MAYNNNE | C602037 | 1 | 1_1 | passive | GNDREF | miscellaneous schematic support | ordinary passive instantiated directly |  |  |  | medium | capacitor with ESR, leakage, ESL and optional DC-bias derating
C10 | 22uF | JLCPCB:C_0805 | SAMSUNG(三星) | CL21A226MAYNNNE | C602037 | 2 | 2_2 | passive | Net-(U7-VOUT) | miscellaneous schematic support | ordinary passive instantiated directly |  |  |  | medium | capacitor with ESR, leakage, ESL and optional DC-bias derating
C11 | 1uF | JLCPCB:C_0402 | SAMSUNG(三星) | CL05A105KA5NQNC | C52923 | 1 | 1_1 | passive | V_Boost | power and precision references | ordinary passive instantiated directly |  |  |  | medium | capacitor with ESR, leakage, ESL and optional DC-bias derating
C11 | 1uF | JLCPCB:C_0402 | SAMSUNG(三星) | CL05A105KA5NQNC | C52923 | 2 | 2_2 | passive | GNDREF | power and precision references | ordinary passive instantiated directly |  |  |  | medium | capacitor with ESR, leakage, ESL and optional DC-bias derating
C12 | 100nF | JLCPCB:C_0402 | SAMSUNG(三星) | CL05B104KO5NNNC | C1525 | 1 | 1_1 | passive | V_Boost | power and precision references | ordinary passive instantiated directly |  |  |  | medium | capacitor with ESR, leakage, ESL and optional DC-bias derating
C12 | 100nF | JLCPCB:C_0402 | SAMSUNG(三星) | CL05B104KO5NNNC | C1525 | 2 | 2_2 | passive | GNDREF | power and precision references | ordinary passive instantiated directly |  |  |  | medium | capacitor with ESR, leakage, ESL and optional DC-bias derating
C13 | 100pF | JLCPCB:C_0402 | FH(风华) | 0402CG101J500NT | C2167113 | 1 | 1_1 | passive | Vm_Ext | external membrane display/output | ordinary passive instantiated directly |  |  |  | medium | capacitor with ESR, leakage, ESL and optional DC-bias derating
C13 | 100pF | JLCPCB:C_0402 | FH(风华) | 0402CG101J500NT | C2167113 | 2 | 2_2 | passive | GNDREF | external membrane display/output | ordinary passive instantiated directly |  |  |  | medium | capacitor with ESR, leakage, ESL and optional DC-bias derating
C14 | 100nF | JLCPCB:C_0402 | SAMSUNG(三星) | CL05B104KO5NNNC | C1525 | 1 | 1_1 | passive | V_Boost | power and precision references | ordinary passive instantiated directly |  |  |  | medium | capacitor with ESR, leakage, ESL and optional DC-bias derating
C14 | 100nF | JLCPCB:C_0402 | SAMSUNG(三星) | CL05B104KO5NNNC | C1525 | 2 | 2_2 | passive | GNDREF | power and precision references | ordinary passive instantiated directly |  |  |  | medium | capacitor with ESR, leakage, ESL and optional DC-bias derating
C15 | 100nF | JLCPCB:C_0402 | SAMSUNG(三星) | CL05B104KO5NNNC | C1525 | 1 | 1_1 | passive | VREF_2V048 | power and precision references | ordinary passive instantiated directly |  |  |  | medium | capacitor with ESR, leakage, ESL and optional DC-bias derating
C15 | 100nF | JLCPCB:C_0402 | SAMSUNG(三星) | CL05B104KO5NNNC | C1525 | 2 | 2_2 | passive | GNDREF | power and precision references | ordinary passive instantiated directly |  |  |  | medium | capacitor with ESR, leakage, ESL and optional DC-bias derating
C16 | 22nF | JLCPCB:C_0402 | SAMSUNG(三星) | CL05B104KO5NNNC | C1532 | 1 | 1_1 | passive | GNDREF | external membrane display/output | ordinary passive instantiated directly |  |  |  | medium | capacitor with ESR, leakage, ESL and optional DC-bias derating
C16 | 22nF | JLCPCB:C_0402 | SAMSUNG(三星) | CL05B104KO5NNNC | C1532 | 2 | 2_2 | passive | Vm_Display_In | external membrane display/output | ordinary passive instantiated directly |  |  |  | medium | capacitor with ESR, leakage, ESL and optional DC-bias derating
C17 | 100nF | JLCPCB:C_0402 | SAMSUNG(三星) | CL05B104KO5NNNC | C1525 | 1 | 1_1 | passive | VDD | local decoupling | ordinary passive instantiated directly |  |  |  | medium | capacitor with ESR, leakage, ESL and optional DC-bias derating
C17 | 100nF | JLCPCB:C_0402 | SAMSUNG(三星) | CL05B104KO5NNNC | C1525 | 2 | 2_2 | passive | GNDREF | local decoupling | ordinary passive instantiated directly |  |  |  | medium | capacitor with ESR, leakage, ESL and optional DC-bias derating
C18 | 470nF | JLCPCB:C_0603 | CCTC(三环) | TCC0603X7R474K500CT | C376839 | 1 | 1_1 | passive | Net-(U9-NO) | membrane capacitance selector | ordinary passive instantiated directly |  |  |  | medium | capacitor with ESR, leakage, ESL and optional DC-bias derating
C18 | 470nF | JLCPCB:C_0603 | CCTC(三环) | TCC0603X7R474K500CT | C376839 | 2 | 2_2 | passive | GNDREF | membrane capacitance selector | ordinary passive instantiated directly |  |  |  | medium | capacitor with ESR, leakage, ESL and optional DC-bias derating
C19 | 100nF | JLCPCB:C_0402 | SAMSUNG(三星) | CL05B104KO5NNNC | C1525 | 1 | 1_1 | passive | VDD | local decoupling | ordinary passive instantiated directly |  |  |  | medium | capacitor with ESR, leakage, ESL and optional DC-bias derating
C19 | 100nF | JLCPCB:C_0402 | SAMSUNG(三星) | CL05B104KO5NNNC | C1525 | 2 | 2_2 | passive | GNDREF | local decoupling | ordinary passive instantiated directly |  |  |  | medium | capacitor with ESR, leakage, ESL and optional DC-bias derating
C20 | 1uF | JLCPCB:C_0603 | muRata(村田) | GRM188R71E105KA12D | C29936 | 1 | 1_1 | passive | Net-(U10-NO) | membrane capacitance selector | ordinary passive instantiated directly |  |  |  | medium | capacitor with ESR, leakage, ESL and optional DC-bias derating
C20 | 1uF | JLCPCB:C_0603 | muRata(村田) | GRM188R71E105KA12D | C29936 | 2 | 2_2 | passive | GNDREF | membrane capacitance selector | ordinary passive instantiated directly |  |  |  | medium | capacitor with ESR, leakage, ESL and optional DC-bias derating
C21 | 100nF | JLCPCB:C_0402 | SAMSUNG(三星) | CL05B104KO5NNNC | C1525 | 1 | 1_1 | passive | VDD | local decoupling | ordinary passive instantiated directly |  |  |  | medium | capacitor with ESR, leakage, ESL and optional DC-bias derating
C21 | 100nF | JLCPCB:C_0402 | SAMSUNG(三星) | CL05B104KO5NNNC | C1525 | 2 | 2_2 | passive | GNDREF | local decoupling | ordinary passive instantiated directly |  |  |  | medium | capacitor with ESR, leakage, ESL and optional DC-bias derating
C22 | 2.2uF | JLCPCB:C_0603 | SAMSUNG(三星) | CL10A225KA8NNNC | C57895 | 1 | 1_1 | passive | Net-(U11-NO) | membrane capacitance selector | ordinary passive instantiated directly |  |  |  | medium | capacitor with ESR, leakage, ESL and optional DC-bias derating
C22 | 2.2uF | JLCPCB:C_0603 | SAMSUNG(三星) | CL10A225KA8NNNC | C57895 | 2 | 2_2 | passive | GNDREF | membrane capacitance selector | ordinary passive instantiated directly |  |  |  | medium | capacitor with ESR, leakage, ESL and optional DC-bias derating
C23 | 100nF | JLCPCB:C_0402 | SAMSUNG(三星) | CL05B104KO5NNNC | C1525 | 1 | 1_1 | passive | VDD | local decoupling | ordinary passive instantiated directly |  |  |  | medium | capacitor with ESR, leakage, ESL and optional DC-bias derating
C23 | 100nF | JLCPCB:C_0402 | SAMSUNG(三星) | CL05B104KO5NNNC | C1525 | 2 | 2_2 | passive | GNDREF | local decoupling | ordinary passive instantiated directly |  |  |  | medium | capacitor with ESR, leakage, ESL and optional DC-bias derating
C24 | 4.7uF | JLCPCB:C_0805 | SAMSUNG(三星) | CL21A475KAQNNNE | C1779 | 1 | 1_1 | passive | Net-(U12-NO) | membrane capacitance selector | ordinary passive instantiated directly |  |  |  | medium | capacitor with ESR, leakage, ESL and optional DC-bias derating
C24 | 4.7uF | JLCPCB:C_0805 | SAMSUNG(三星) | CL21A475KAQNNNE | C1779 | 2 | 2_2 | passive | GNDREF | membrane capacitance selector | ordinary passive instantiated directly |  |  |  | medium | capacitor with ESR, leakage, ESL and optional DC-bias derating
C25 | 100nF | JLCPCB:C_0402 | SAMSUNG(三星) | CL05B104KO5NNNC | C1525 | 1 | 1_1 | passive | VDD | local decoupling | ordinary passive instantiated directly |  |  |  | medium | capacitor with ESR, leakage, ESL and optional DC-bias derating
C25 | 100nF | JLCPCB:C_0402 | SAMSUNG(三星) | CL05B104KO5NNNC | C1525 | 2 | 2_2 | passive | GNDREF | local decoupling | ordinary passive instantiated directly |  |  |  | medium | capacitor with ESR, leakage, ESL and optional DC-bias derating
C26 | 10uF | JLCPCB:C_0805 | HRE(芯声) | CGA0805X7R106K250MT | C40894 | 1 | 1_1 | passive | Net-(U13-NO) | membrane capacitance selector | ordinary passive instantiated directly |  |  |  | medium | capacitor with ESR, leakage, ESL and optional DC-bias derating
C26 | 10uF | JLCPCB:C_0805 | HRE(芯声) | CGA0805X7R106K250MT | C40894 | 2 | 2_2 | passive | GNDREF | membrane capacitance selector | ordinary passive instantiated directly |  |  |  | medium | capacitor with ESR, leakage, ESL and optional DC-bias derating
C27 | 100nF | JLCPCB:C_0402 | SAMSUNG(三星) | CL05B104KO5NNNC | C1525 | 1 | 1_1 | passive | VDD | local decoupling | ordinary passive instantiated directly |  |  |  | medium | capacitor with ESR, leakage, ESL and optional DC-bias derating
C27 | 100nF | JLCPCB:C_0402 | SAMSUNG(三星) | CL05B104KO5NNNC | C1525 | 2 | 2_2 | passive | GNDREF | local decoupling | ordinary passive instantiated directly |  |  |  | medium | capacitor with ESR, leakage, ESL and optional DC-bias derating
C28 | 100pF | JLCPCB:C_0402 | FH(风华) | 0402CG101J500NT | C2167113 | 1 | 1_1 | passive | GNDREF | membrane leak and integration | ordinary passive instantiated directly |  |  |  | medium | capacitor with ESR, leakage, ESL and optional DC-bias derating
C28 | 100pF | JLCPCB:C_0402 | FH(风华) | 0402CG101J500NT | C2167113 | 2 | 2_2 | passive | Vm_Int | membrane leak and integration | ordinary passive instantiated directly |  |  |  | medium | capacitor with ESR, leakage, ESL and optional DC-bias derating
C29 | 1uF | JLCPCB:C_0603 | muRata(村田) | GRM188R71E105KA12D | C29936 | 1 | 1_1 | passive | /Vkick | adaptation | ordinary passive instantiated directly |  |  |  | medium | capacitor with ESR, leakage, ESL and optional DC-bias derating
C29 | 1uF | JLCPCB:C_0603 | muRata(村田) | GRM188R71E105KA12D | C29936 | 2 | 2_2 | passive | /Adapt_Kick_Drive | adaptation | ordinary passive instantiated directly |  |  |  | medium | capacitor with ESR, leakage, ESL and optional DC-bias derating
C30 | 10uF | JLCPCB:C_0805 | SAMSUNG(三星) | CL05A106MP5NUNC | C15850 | 1 | 1_1 | passive | GNDREF | adaptation | ordinary passive instantiated directly |  |  |  | medium | capacitor with ESR, leakage, ESL and optional DC-bias derating
C30 | 10uF | JLCPCB:C_0805 | SAMSUNG(三星) | CL05A106MP5NUNC | C15850 | 2 | 2_2 | passive | Vw | adaptation | ordinary passive instantiated directly |  |  |  | medium | capacitor with ESR, leakage, ESL and optional DC-bias derating
C31 | 10nF | JLCPCB:C_0402 | Samsung Electro-Mechanics |  | C15195 | 1 |  | passive | AP | threshold, AP, peak, reset and spike output | ordinary passive instantiated directly |  |  |  | medium | capacitor with ESR, leakage, ESL and optional DC-bias derating
C31 | 10nF | JLCPCB:C_0402 | Samsung Electro-Mechanics |  | C15195 | 2 |  | passive | /Rising_AP | threshold, AP, peak, reset and spike output | ordinary passive instantiated directly |  |  |  | medium | capacitor with ESR, leakage, ESL and optional DC-bias derating
C32 | 100nF | JLCPCB:C_0402 | SAMSUNG(三星) | CL05B104KO5NNNC | C1525 | 1 | 1_1 | passive | VDD | local decoupling | ordinary passive instantiated directly |  |  |  | medium | capacitor with ESR, leakage, ESL and optional DC-bias derating
C32 | 100nF | JLCPCB:C_0402 | SAMSUNG(三星) | CL05B104KO5NNNC | C1525 | 2 | 2_2 | passive | GNDREF | local decoupling | ordinary passive instantiated directly |  |  |  | medium | capacitor with ESR, leakage, ESL and optional DC-bias derating
C33 | 1uF | JLCPCB:C_0402 | SAMSUNG(三星) | CL05A105KA5NQNC | C52923 | 1 | 1_1 | passive | GNDREF | miscellaneous schematic support | ordinary passive instantiated directly |  |  |  | medium | capacitor with ESR, leakage, ESL and optional DC-bias derating
C33 | 1uF | JLCPCB:C_0402 | SAMSUNG(三星) | CL05A105KA5NQNC | C52923 | 2 | 2_2 | passive | Net-(U6C-INC-) | miscellaneous schematic support | ordinary passive instantiated directly |  |  |  | medium | capacitor with ESR, leakage, ESL and optional DC-bias derating
C34 | 100nF | JLCPCB:C_0402 | SAMSUNG(三星) | CL05B104KO5NNNC | C1525 | 1 | 1_1 | passive | VDD | local decoupling | ordinary passive instantiated directly |  |  |  | medium | capacitor with ESR, leakage, ESL and optional DC-bias derating
C34 | 100nF | JLCPCB:C_0402 | SAMSUNG(三星) | CL05B104KO5NNNC | C1525 | 2 | 2_2 | passive | GNDREF | local decoupling | ordinary passive instantiated directly |  |  |  | medium | capacitor with ESR, leakage, ESL and optional DC-bias derating
C35 | 100nF | JLCPCB:C_0402 | SAMSUNG(三星) | CL05B104KO5NNNC | C1525 | 1 | 1_1 | passive | VDD | local decoupling | ordinary passive instantiated directly |  |  |  | medium | capacitor with ESR, leakage, ESL and optional DC-bias derating
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

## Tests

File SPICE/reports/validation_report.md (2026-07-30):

# LIFeling SPICE reconstruction and validation report

## Executive conclusion

The electrical model was reconstructed from the attached KiCad export dated **2026-07-29T20:56:15**, produced by **Eeschema 10.0.1**. The export contains **216 components** and **112 nets**. Connectivity in generated decks is derived from physical pins in that export; intended equations and previous behavioural mappings are not used as connectivity sources.

The static topology audit has **0 blocking failures** and **3 explicit warnings**. No blocking topology failure remains.

Transient execution status: **48 passed**, **0 failed**, **0 not executed**. A non-executed run is not reported as electrical validation.

Static reconstruction tests: **0 passed, 0 failures, 0 errors** (skipped).

> This system validates a SPICE representation. It does not constitute hardware validation, ESD qualification, battery-life certification, sustained-fault survival proof, PCB-parasitic validation, or production test evidence.

## 1. Source and version lock

- Authoritative netlist SHA-256: `d5a0bf3aa70e19a4470710342be6b2e11441efbc97374f23ff95af703fe9eeea`
- Stable source-lock SHA-256: `55df884890c53c1af35b7f03e638c13b9e68e5c5d7e3ac005e109ba13a78201c`
- Full run-manifest SHA-256: `3f0746a8e6198edcea1070234103bbd79e6cfbd6e052a2894bebc786696f99df`
- KiCad source recorded in export: `C:\Users\mjyzi\Documents\GitHub\LIFeling\PCBs\LIFeling\LIFeling.kicad_sch`
- Export date: `2026-07-29T20:56:15`
- KiCad tool: `Eeschema 10.0.1`
- Repository comparison commit: `272b9b74c9f78c5c64ee9d9609b1ea035339ad1e`
- Repository commit date: `2026-07-08T10:47:48Z`
- Attached files newer than repository comparison: **yes**

When attached and repository files differ, the attached netlist controls electrical connectivity. The schematic is a visual cross-check. The earlier Python implementation and historical outputs are comparison material only.

Schematic cross-check: **416 placed symbols**, **0 blocking mismatches**, **0 metadata warnings**. Escaped KiCad property strings are decoded before comparison, so the BT1 simulation-parameter value is compared exactly rather than truncated.

### Source hashes

| File | Type | Bytes | SHA-256 |
|---|---|---:|---|
| `LIFeling(2).net` | authoritative KiCad netlist | 818149 | `d5a0bf3aa70e19a4470710342be6b2e11441efbc97374f23ff95af703fe9eeea` |
| `LIFeling(1).kicad_sch` | latest attached KiCad schematic cross-check | 2117205 | `9971cd95cc7011216b15f5ae127d027145e486473367b6c6d7d025a09745f5dd` |
| `Spice.py` | previous simulator comparison only | 117013 | `ee80d67884d0251fd4be509421c598d7f54c33abc61fb264b8e0f9e031878975` |
| `run_full_validation.ps1` | previous runner comparison only | 21524 | `c4e7164bf972fe5fc2df11760d341ab6fec97b3cfbc8d3f28c87cc4e7528fb34` |
| `1n4148_spice.lib` | provided vendor/cross-vendor model | 1629 | `f48fd3b8722660f0dc06039a58b67a6b6423628b10276128246971aa5b78be47` |
| `lm2901.lib` | provided legacy/unused comparator model | 7521 | `622338a26a2f7cd185f254f7596c729f52e8c8ac69585009a8feae129c8d7296` |
| `MCP6001.txt` | provided official Microchip family model | 5990 | `c510804933f8b3224f7c0b2064c98f7728ec81d3ce2052046a9b754dd8d482bf` |
| `MCP6001_ngspice.lib` | ngspice syntax-normalised copy of official Microchip family model | 6101 | `982f2bf0b7d801135bb665831d4e3c2053b3ff0ff6a19948eabf69fe772ffdd6` |
| `MMBT3904.spice.txt` | provided cross-manufacturer discrete model | 1587 | `49c344a0aaa461869b9a6f7a67e8afc0afbb0050a6b4f7e19e44025b076a6d2d` |
| `BOM.csv` | uploaded supplementary BOM context; not authoritative for connectivity | 17833216 | `657aa5d14b832c269e664859ccc5e4f8da446c86de3a581b27c9f7f8bb221b48` |

## 2. Verified hardware corrections

### U4 uses the corrected TLV7044 PW-14 physical pin order.

**PASS.** All 14 physical pin functions match.

### U5 uses the corrected TLV7044 PW-14 physical pin order.

**PASS.** All 14 physical pin functions match.

### U6 uses the corrected TLV7044 PW-14 physical pin order.

**PASS.** All 14 physical pin functions match.

### MCP6004 physical package pins match the approved package map for U1, U2, U3.

**PASS.** All physical pin functions match.

### TLV9001 physical package pins match the approved package map for U8, U22.

**PASS.** All physical pin functions match.

### TLV9041 physical package pins match the approved package map for U23.

**PASS.** All physical pin functions match.

### TLV7031 physical package pins match the approved package map for U19.

**PASS.** All physical pin functions match.

### TS5A3166 physical package pins match the approved package map for U9, U10, U11, U12, U13, U14, U15, U16, U17, U18, U20.

**PASS.** All physical pin functions match.

### TPS610995 physical package pins match the approved package map for U7.

**PASS.** All physical pin functions match.

### RV4 selector comparator polarity is derived from physical pins and forms the intended five windows.

**PASS.** Physical comparator channels match the one-hot window equations.

### RV4 selects 470 nF, 1 µF, 2.2 µF, 4.7 µF, then 10 µF through U9–U13.

**PASS.** Monotonic physical switch/capacitor chain confirmed.

### Peak_Window is an active-high event pulse generated by U6A and pulled up by R51.

**PASS.** U6A pins: OUT=Peak_Window, IN+=Spike_Pulse, IN-=V_Threshold; R51=['Peak_Window', 'VDD']; U14/U20 controls=[('U14', '4'), ('U20', '4')].

### U23 is the physical TLV9041 stimulus amplifier and all four gain-setting resistors are present.

**PASS.** Electrical topology matches the intended transfer; the output-to-Vm resistor is physically R96, not R97.

### The latest electrical topology uses R96 between V_Stim_Drive and Vm_Int, while the requested design note calls this resistor R97.

**WARNING.** R97 is absent. R96 is 100 kΩ between V_Stim_Drive and Vm_Int; there is no VDD pull-up on V_Stim_Drive.

### U6B is unused and forced into a deterministic state.

**PASS.** INB+=VDD, INB-=GNDREF, OUTB=unconnected-(U6B-OUTB-Pad7)

### The fitted TPS610995DRVR is the fixed 3.6 V variant, not the 3.3 V TPS610994 variant.

**WARNING.** Netlist U7 value=TPS610995DRVR. Portable switching model VSET is locked to 3.6 V; previous 3.3 V behavioural assumptions are rejected.

### REF3020AIDBZR physical DBZ package pins match the official IN=1, OUT=2, GND=3 order.

**PASS.** KiCad mapping: pin1=VDD, pin2=VREF_2V048, pin3=GNDREF.

## 3. Important netlist findings

1. The TLV7044 channel-A correction is present on U4, U5 and U6 and the full physical PW-14 mapping is audited before channel instances are emitted.
2. RV4’s five comparator windows and TS5A3166/capacitor mapping are generated from physical comparator inputs and switch pins. The intended monotonic sequence is confirmed by topology, not hard-coded as a selector outcome.
3. `Peak_Window` is physically active-high: U6A compares `Spike_Pulse` at IN+ against `V_Threshold` at IN−, R51 pulls up the open-drain output, and U14/U20 use that node as an active-high control.
4. U23 is a physical TLV9041 stage with R92–R95 forming the closed-loop network. The transfer is not replaced by a behavioural voltage source.
5. The output-to-`Vm_Int` resistor is **R96 = 100 kΩ** in the attached export. **R97 is absent.** Electrically this is the intended injection resistor, but the designator differs from the requested description.
6. U6B is unused: INB+ is tied to VDD, INB− to GNDREF, and OUTB is unconnected.
7. U7 is `TPS610995DRVR`, which is the fixed 3.6 V member. The prior hard-coded 3.3 V boost assumption is rejected; 3.3 V would correspond to TPS610994.
8. REF3020 KiCad physical pins are pin 1 input, pin 2 output and pin 3 ground. A downloaded TINA macro-model is never instantiated until its actual terminal declaration is inspected and wrapped.

## 4. Model coverage and hierarchy

The default `hybrid` profile uses the supplied official Microchip MCP6001/2/4 family macro-model for all twelve MCP6004 channels and documented portable models for devices whose official packages are not yet installed and smoke-tested. `pin_model_mapping.csv` records every active/discrete physical pin, connected net, wrapper terminal and model terminal. The `vendor` profile is intentionally strict: it fails rather than silently substituting an unapproved model or guessed terminal order.

| Family | References | Selected status | Model/subcircuit | Confidence | Known limitation |
|---|---|---|---|---|---|
| `MCP6004T-I/ST` | U1, U2, U3 | installed vendor/model source | `MCP6001` | high | Inspected .SUBCKT at MCP6001_ngspice.lib:5. |
| `TLV7044PWR` | U4, U5, U6 | portable fallback | `portable rule` | medium | Official package is not installed/verified; using documented portable model. |
| `TLV7031DCKR` | U19 | portable fallback | `portable rule` | medium | Official package is not installed/verified; using documented portable model. |
| `TLV9001IDBVR` | U22, U8 | portable fallback | `portable rule` | medium | Official package is not installed/verified; using documented portable model. |
| `TLV9041IDBVR` | U23 | portable fallback | `portable rule` | medium | Official package is not installed/verified; using documented portable model. |
| `TS5A3166DCKR` | U10, U11, U12, U13, U14, U15, U16, U17, U18, U20, U9 | portable fallback | `portable rule` | medium | Official package is not installed/verified; using documented portable model. |
| `TPS610995DRVR` | U7 | portable fallback | `portable rule` | medium | Official package is not installed/verified; using documented portable model. |
| `REF3020AIDBZR` | U21 | portable fallback | `portable rule` | medium | Official package is not installed/verified; using documented portable model. |
| `TPD1E05U06DPYT` | D1, D18, D19 | portable fallback | `portable rule` | medium | Official package is not installed/verified; using documented portable model. |
| `BSS138` | Q1, Q3, Q4, Q5, Q6, Q7 | portable fallback | `portable rule` | medium | Official package is not installed/verified; using documented portable model. |
| `MMBT3904` | Q2, Q8 | installed comparison model; portable fallback selected | `models\provided\MMBT3904.spice.txt` | medium | Inspected .MODEL DI_MMBT3904 (NPN) at MMBT3904.spice.txt:18. The supplied model manufacturer does not match the ordered/netlist manufacturer and is not instantiated by the hybrid deck. |
| `BAT54WS L9` | D10, D11, D12, D13, D14, D15, D16, D17, D2, D21, D22, D3 | portable fallback | `portable rule` | medium | Official package is not installed/verified; using documented portable model. |
| `1N4148WS` | D4, D5, D7 | installed comparison model; portable fallback selected | `1N4148` | medium | Inspected .SUBCKT at 1n4148_spice.lib:14. The supplied model manufacturer does not match the ordered/netlist manufacturer and is not instantiated by the hybrid deck. |
| `RB521S30T1G` | D20, D6, D8 | portable fallback | `portable rule` | medium | Official package is not installed/verified; using documented portable model. |
| `19-237/R6GHBHC-A01/2T` | D9 | portable fallback | `portable rule` | medium | Official package is not installed/verified; using documented portable model. |
| `CR2032` | BT1 | portable fallback | `portable rule` | medium | Official package is not installed/verified; using documented portable model. |
| `ANR3015T2R2M` | L1 | portable fallback | `portable rule` | medium | Official package is not installed/verified; using documented portable model. |

### Explicit approximations remaining in the portable/hybrid profile

- TLV7044 and TLV7031: rail-aware comparator wrappers include open-drain/push-pull topology, quiescent current, finite output resistance, input loading, hysteresis and a propagation-delay pole. They are not substitutes for the official TI model’s complete overdrive and supply dependence.
- TLV9001 and TLV9041: finite open-loop gain, dominant pole, rail clipping, output resistance and quiescent current are represented. Input offset, detailed output-current limiting and every datasheet corner are not fully reproduced.
- TS5A3166: active-high supply-referenced logic, on-resistance, leakage and capacitance are represented. Charge injection, exact powered-off isolation and process corners remain approximate.
- TPS610995: the fallback is a 3.6 V switching macro-model using the physical L1 and output capacitors. It is not an official efficiency or control-loop sign-off model. The official unencrypted transient package should be smoke-tested separately before replacing it.
- REF3020: startup, dropout, finite source resistance, source-only behaviour and quiescent current are approximated. Noise and complete line/load-regulation surfaces are not sign-off quality.
- TPD1E05U06: capacitance, leakage, breakdown and dynamic resistance are datasheet-derived. This cannot prove IEC ESD robustness or sustained overvoltage survival.
- CR2032: the actual cell manufacturer is unspecified; both fixed source-resistance sweeps and a dynamic equivalent are supported, but battery-life predictions are provisional.
- L1 and MLCCs: DCR/ESR/ESL, tolerance, leakage and conservative DC-bias derating are included. Exact vendor nonlinear curves are not embedded unless supplied.
- BSS138, MMBT3904, BAT54WS, 1N4148WS, RB521S30 and the RGB LED use explicit vendor-mismatch or datasheet-derived models where an exact ordered-part model was unavailable.

## 5. Validation test matrix

| Test | Purpose | Acceptance evidence | Hardware claim allowed? |
|---|---|---|---|
| Full operating transient | Integrate, threshold, AP, peak, reset, adaptation, synapse, outputs | Numeric edge counts, rail ranges, periods and trace CSV | No; functional SPICE correlation only |
| RV4 selector sweep | Confirm one-hot physical comparator/switch selection over five regions | S0–S4 states and effective membrane transient ordering | No |
| U23 stimulus transfer sweep | Confirm gain, polarity, clipping, settling and injection current emerge from U23/R92–R96 | `V_Stim_Drive - [Vm_Int + 0.5(V_Stim_Cmd−VREF)]` error inside linear region | No |
| Peak-window event | Confirm active-high `Peak_Window`, U14/U20 closure and positive external pulse | event timing and polarity | No |
| Cold and low-battery startup | Check reference, comparator and boost startup under source impedance | startup time, rail sag, failure mode | No battery-life or safety claim |
| Synapse sign and decay sweeps | Confirm midpoint neutrality, excitatory/inhibitory polarity and RV5 decay | differential Vm response and state decay | No |
| Tolerance/temperature Monte Carlo | Identify functional margins and fragile parameter combinations | percentile distributions and failing seeds | No production yield claim without measured distributions |

## 6. Execution record

| Test | Status | ngspice | Message |
|---|---|---|---|
| `01_full_operating` | **passed** | ngspice-46 : Circuit level simulation program | completed |
| `02_peak_window_active_high` | **passed** | ngspice-46 : Circuit level simulation program | completed |
| `03_stimulus_transfer_0V` | **passed** | ngspice-46 : Circuit level simulation program | completed |
| `04_stimulus_transfer_1V024` | **passed** | ngspice-46 : Circuit level simulation program | completed |
| `05_stimulus_transfer_2V048` | **passed** | ngspice-46 : Circuit level simulation program | completed |
| `06_cold_start_dynamic_battery` | **passed** | ngspice-46 : Circuit level simulation program | completed |
| `07_low_battery_high_impedance` | **passed** | ngspice-46 : Circuit level simulation program | completed |
| `08_synapse_midpoint` | **passed** | ngspice-46 : Circuit level simulation program | completed |
| `09_power_switch_off` | **passed** | ngspice-46 : Circuit level simulation program | completed |
| `10_vm_ext_loaded_10k` | **passed** | ngspice-46 : Circuit level simulation program | completed |
| `11_spike_out_loaded_10k` | **passed** | ngspice-46 : Circuit level simulation program | completed |
| `20_rv4_selector_region_1` | **passed** | ngspice-46 : Circuit level simulation program | completed |
| `20_rv4_selector_region_2` | **passed** | ngspice-46 : Circuit level simulation program | completed |
| `20_rv4_selector_region_3` | **passed** | ngspice-46 : Circuit level simulation program | completed |
| `20_rv4_selector_region_4` | **passed** | ngspice-46 : Circuit level simulation program | completed |
| `20_rv4_selector_region_5` | **passed** | ngspice-46 : Circuit level simulation program | completed |
| `30_rv1_leak_1` | **passed** | ngspice-46 : Circuit level simulation program | completed |
| `30_rv1_leak_2` | **passed** | ngspice-46 : Circuit level simulation program | completed |
| `30_rv1_leak_3` | **passed** | ngspice-46 : Circuit level simulation program | completed |
| `31_rv2_leak_rate_1` | **passed** | ngspice-46 : Circuit level simulation program | completed |
| `31_rv2_leak_rate_2` | **passed** | ngspice-46 : Circuit level simulation program | completed |
| `31_rv2_leak_rate_3` | **passed** | ngspice-46 : Circuit level simulation program | completed |
| `32_rv3_adaptation_1` | **passed** | ngspice-46 : Circuit level simulation program | completed |
| `32_rv3_adaptation_2` | **passed** | ngspice-46 : Circuit level simulation program | completed |
| `32_rv3_adaptation_3` | **passed** | ngspice-46 : Circuit level simulation program | completed |
| `33_rv5_synapse_decay_1` | **passed** | ngspice-46 : Circuit level simulation program | completed |
| `33_rv5_synapse_decay_2` | **passed** | ngspice-46 : Circuit level simulation program | completed |
| `33_rv5_synapse_decay_3` | **passed** | ngspice-46 : Circuit level simulation program | completed |
| `40_rv6_syn1_low` | **passed** | ngspice-46 : Circuit level simulation program | completed |
| `40_rv6_syn1_mid` | **passed** | ngspice-46 : Circuit level simulation program | completed |
| `40_rv6_syn1_high` | **passed** | ngspice-46 : Circuit level simulation program | completed |
| `40_rv7_syn2_low` | **passed** | ngspice-46 : Circuit level simulation program | completed |
| `40_rv7_syn2_mid` | **passed** | ngspice-46 : Circuit level simulation program | completed |
| `40_rv7_syn2_high` | **passed** | ngspice-46 : Circuit level simulation program | completed |
| `40_rv8_syn3_low` | **passed** | ngspice-46 : Circuit level simulation program | completed |
| `40_rv8_syn3_mid` | **passed** | ngspice-46 : Circuit level simulation program | completed |
| `40_rv8_syn3_high` | **passed** | ngspice-46 : Circuit level simulation program | completed |
| `40_rv9_syn4_low` | **passed** | ngspice-46 : Circuit level simulation program | completed |
| `40_rv9_syn4_mid` | **passed** | ngspice-46 : Circuit level simulation program | completed |
| `40_rv9_syn4_high` | **passed** | ngspice-46 : Circuit level simulation program | completed |
| `50_temperature_m20p0C` | **passed** | ngspice-46 : Circuit level simulation program | completed |
| `50_temperature_25p0C` | **passed** | ngspice-46 : Circuit level simulation program | completed |
| `50_temperature_60p0C` | **passed** | ngspice-46 : Circuit level simulation program | completed |
| `60_tolerance_seed_1` | **passed** | ngspice-46 : Circuit level simulation program | completed |
| `60_tolerance_seed_2` | **passed** | ngspice-46 : Circuit level simulation program | completed |
| `60_tolerance_seed_3` | **passed** | ngspice-46 : Circuit level simulation program | completed |
| `60_tolerance_seed_4` | **passed** | ngspice-46 : Circuit level simulation program | completed |
| `60_tolerance_seed_5` | **passed** | ngspice-46 : Circuit level simulation program | completed |

## 7. Build gates

The build fails when any new active component lacks a registry rule, any functional reference/net is absent, any required installed model is missing in strict-vendor mode, a named subcircuit cannot be found, a locked terminal count/order disagrees, or any exported reference is neither instantiated nor deliberately classified as terminal/mechanical.

## 8. Required bench correlation before production

The final PCB should be correlated at minimum for VDD/boost startup, 2.048 V and 1.024 V references, RV4 one-hot selection, U23 gain/clipping, AP/Peak/Reset timing, Spike_Out levels into representative loads, synaptic midpoint neutrality, quiescent current, CR2032 pulse sag, output protection under realistic classroom faults, and temperature/tolerance extremes. Those measurements should be stored beside the SPICE CSVs with board serial number, instruments, probe points and firmware/test conditions.

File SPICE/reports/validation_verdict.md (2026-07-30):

# LIFeling SPICE validation verdict

Source lock SHA-256: `55df884890c53c1af35b7f03e638c13b9e68e5c5d7e3ac005e109ba13a78201c`

| Block | Status | Evidence | Limitation |
|---|---|---|---|
| Simulation execution | **PASS** | 48 decks; 0 failed; 0 not executed. |  |
| Power and reference rails | **WARNING** | V_Boost=0.66170496; VREF_2V048=0.296546701; VREF_1V024=0.680819542. | Portable models are not production sign-off models. |
| Core LIF activity | **WARNING** | AP rising edges=0; Vm threshold crossings=0. |  |
| Active-high Peak_Window and Spike_Out | **WARNING** | Peak_Window edges=0; Spike_Out edges=0. |  |
| U23 closed-loop stimulus transfer | **WARNING** | Maximum linear-equation residual=unavailable V. | Residual is interpreted only while U23 is not clipping. |
| RV4 one-hot monotonic selector | **WARNING** | Observed high outputs=[['S0'], ['S0', 'S1'], ['S1', 'S2'], ['S3'], ['S4']]. |  |
| Power-off state | **PASS** | VDD_end=0.000876163986 V. |  |
| Cold-start and low-battery operation | **WARNING** | 06_cold_start_dynamic_battery: VDD=-7.69570818e-06..0.701003027 V, VREF2=0.438434053 V; 07_low_battery_high_impedance: VDD=1.40656109e-05..0.701002906 V, VREF2=0.555849644 V | Battery chemistry and converter fallback remain approximate. |
| External output loading | **WARNING** | 10 kOhm Vm_Ext peak reduction=0.004176555000000026 V; loaded Spike_Out edges=0. |  |
| RV1 leak-reference control | **PASS** | V_Leak end values=[0.0290713251, 0.147139142, 0.265378656]. |  |
| RV2 membrane-leak-rate control | **WARNING** | AP periods=[]; Vm_Int maxima=[0.0114157916, 0.0103844092, 0.00979871664]. |  |
| RV3 adaptation control | **WARNING** | Vw maxima=[1.79897911e-05, 1.79881874e-05, 1.79738852e-05]; AP periods=[]. |  |
| RV5 synaptic-decay control | **PASS** | V_Syn_State end values=[0.00465864659, 0.00772245929, 0.0227512323]. |  |
| Synaptic sign, midpoint and RV6-RV9 weight controls | **WARNING** | Syn1 Vm_Int max low/mid/high=[0.0103856783, 0.0103856701, 0.0103857277]; state max=[0.00772414644, 0.00772245929, 0.00772808764]; Syn2 Vm_Int max low/mid/high=[0.0103856899, 0.0103857213, 0.0103857613]; state max=[0.00771691551, 0.00772245932, 0.00772808738]; Syn3 Vm_Int max low/mid/high=[0.0103856221, 0.010385709, 0.0103857029]; state max=[0.00771691524, 0.00772245556, 0.0077280878]; Syn4 Vm_Int max low/mid/high=[0.0103857514, 0.0103856813, 0.010385788]; state max=[0.00771691489, 0.00772245568, 0.00772808792] | Direction is checked at the physical membrane response; exact biological equivalence is not claimed. |
| Temperature sweep | **WARNING** | 50_temperature_25p0C: VDD_end=0.70100329, AP=0; 50_temperature_60p0C: VDD_end=0.701876064, AP=0; 50_temperature_m20p0C: VDD_end=0.701003343, AP=1 | Portable model temperature laws are incomplete. |
| Component-tolerance seeds | **WARNING** | Five deterministic seeds executed; rail-level failures=['60_tolerance_seed_1', '60_tolerance_seed_2', '60_tolerance_seed_3', '60_tolerance_seed_4', '60_tolerance_seed_5']. | Five seeds are a regression screen, not a production-yield Monte Carlo study. |
| ESD and sustained external-fault survival | **NOT CLAIMED** | Protection devices are represented only for normal-signal loading and limited clamp-transient exploration. | No SPICE result from this suite constitutes IEC ESD qualification or sustained-overvoltage survival proof. |

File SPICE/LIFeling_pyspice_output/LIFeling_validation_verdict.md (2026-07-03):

# LIFeling SPICE validation verdict

Script version: `validation-suite-v6-readme-walkthrough`
Overall verdict: **PASS WITH WARNINGS**

Validation suite: `43` total steps, `0` failed.

## Block-level verdict

| Circuit block | Verdict | Evidence | Caveat |
|---|---|---|---|
| Simulation execution / convergence | **PASS** | 43 suite steps, 0 failed. |  |
| Component model coverage | **PASS** | behavioural: 36, electrical: 165, mechanical: 6, terminal: 6 | Behavioural entries are intentional circuit-block approximations, not vendor-accurate macromodels. |
| Reference rails VREF_2V048 / VREF_1V024 | **PASS** | Baseline VREF_2V048=2.048..2.048 V; VREF_1V024=1.024..1.024 V. |  |
| Core LIF oscillation / threshold / AP / reset / Spike_Out | **PASS** | Baseline AP=27, Reset_Window=27, Spike_Out=27; Vm_Int=0.4637..0.8832 V. |  |
| Quiet subthreshold operating point | **PASS** | Quiet-subthreshold AP_rising_edges=0; Vm_Int_max=0.51 V. |  |
| Cold-start behaviour | **PASS** | Cold-start AP_rising_edges=58; Vm_Int_max=1.632 V. | Cold-start is a stress condition, not the normal operating initial condition. |
| Synapse midpoint zero-effect | **PASS** | Midpoint minus quiet Vm_Int_max delta=0.7374 mV; AP_rising_edges=0. |  |
| Excitatory synapse sign | **PASS** | Excitatory minus quiet Vm_Int_max delta=118.3 mV. |  |
| Inhibitory synapse sign | **PASS** | Baseline AP period=53.89 ms; inhibitory AP period=70.03 ms. |  |
| External stimulus path | **WARNING** | Positive stimulus delta=-61.95 mV; negative stimulus delta=-85.12 mV. | If this warns, run a dedicated Stimulus_Ext -> V_Stim_Drive -> Vm_Int polarity sweep. |
| RV1 leak/reference sweep | **PASS** | First sweep AP edges=0; last sweep AP edges=18. |  |
| RV2 leak-rate sweep | **PASS** | Finite AP mean periods observed: 53.81 ms, 28.07 ms. |  |
| RV3 adaptation sweep | **PASS** | 4 RV3 adaptation sweep runs completed. | Interpretation should verify that the knob direction matches the front-panel label. |
| RV4 capacitance-bank sweep | **PASS** | 5 RV4 capacitance-bank sweep runs completed. | A dedicated Cmem-selection table can be added later if exact one-hot switch state is required. |
| RV5 synaptic decay sweep | **PASS** | 5 RV5 synaptic decay sweep runs completed. | Interpretation should verify that the knob direction matches the front-panel label. |
| Synaptic sign/weight sweep | **PASS** | 5 synaptic sign/weight sweep runs completed. |  |
| Low-battery / high-impedance stress | **WARNING** | VDD_min=2.518 V; estimated peak battery current=1.516 mA; Spike_Pulse_max=0.9884 V. | Spike_Pulse edge counting may need a lower/comparator-relative threshold in low-battery conditions. |

## Generated files

- `validation_diagnostics_summary.csv`: aggregate numerical diagnostics, one row per validation run.
- `component_model_coverage.csv`: electrical/behavioural/mechanical model coverage for schematic components.
- `LIFeling_validation_verdict.csv`: machine-readable block-level verdict.
- `LIFeling_key_validation_metrics.csv`: selected regression metrics.

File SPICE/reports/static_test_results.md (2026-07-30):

# LIFeling static reconstruction tests

Status: **PASSED**

Tests run: **30**; failures: **0**; errors: **0**.

Execution mode: **in-process unittest runner**.

```text
test_n06_uses_ramped_fixed_soc_thevenin_source (test_cold_start_thevenin.ColdStartTheveninRegression.test_n06_uses_ramped_fixed_soc_thevenin_source) ... ok
test_dynamic_battery_subcircuit_is_present (test_dynamic_battery_ngspice.DynamicBatteryNgspiceRegression.test_dynamic_battery_subcircuit_is_present) ... ok
test_ocv_uses_behavioural_voltage_source (test_dynamic_battery_ngspice.DynamicBatteryNgspiceRegression.test_ocv_uses_behavioural_voltage_source) ... ok
test_cold_start_has_bounded_horizon_and_focused_outputs (test_dynamic_battery_runtime.DynamicBatteryRuntimeRegression.test_cold_start_has_bounded_horizon_and_focused_outputs) ... ok
test_dynamic_battery_uses_linear_controlled_soc_current (test_dynamic_battery_runtime.DynamicBatteryRuntimeRegression.test_dynamic_battery_uses_linear_controlled_soc_current) ... ok
test_all_modelled_ic_package_pin_maps_pass (test_static.LIFelingStaticValidation.test_all_modelled_ic_package_pin_maps_pass) ... ok
test_all_subcircuit_instances_resolve_in_packaged_libraries (test_static.LIFelingStaticValidation.test_all_subcircuit_instances_resolve_in_packaged_libraries) ... ok
test_authoritative_source_lock (test_static.LIFelingStaticValidation.test_authoritative_source_lock) ... ok
test_coverage_has_no_unresolved_reference (test_static.LIFelingStaticValidation.test_coverage_has_no_unresolved_reference) ... ok
test_deck_fingerprint_is_deterministic_for_same_source_lock (test_static.LIFelingStaticValidation.test_deck_fingerprint_is_deterministic_for_same_source_lock) ... ok
test_deck_has_physical_u23_and_no_silent_omission (test_static.LIFelingStaticValidation.test_deck_has_physical_u23_and_no_silent_omission) ... ok
test_dynamic_battery_discharge_reduces_soc (test_static.LIFelingStaticValidation.test_dynamic_battery_discharge_reduces_soc) ... ok
test_generated_deck_includes_ngspice_compatible_mcp_model (test_static.LIFelingStaticValidation.test_generated_deck_includes_ngspice_compatible_mcp_model) ... ok
test_mcp6001_ngspice_copy_normalises_resistor_tc_syntax (test_static.LIFelingStaticValidation.test_mcp6001_ngspice_copy_normalises_resistor_tc_syntax) ... ok
test_megohm_is_not_milliohm (test_static.LIFelingStaticValidation.test_megohm_is_not_milliohm) ... ok
test_official_mcp_model_declaration (test_static.LIFelingStaticValidation.test_official_mcp_model_declaration) ... ok
test_open_drain_comparator_polarity_releases_when_plus_is_higher (test_static.LIFelingStaticValidation.test_open_drain_comparator_polarity_releases_when_plus_is_higher) ... ok
test_peak_window_is_active_high_physical_comparator (test_static.LIFelingStaticValidation.test_peak_window_is_active_high_physical_comparator) ... ok
test_portable_boost_oscillator_uses_ngspice_supported_pulse_source (test_static.LIFelingStaticValidation.test_portable_boost_oscillator_uses_ngspice_supported_pulse_source) ... ok
test_provided_mmbt3904_model_card_is_detected_but_not_claimed_exact (test_static.LIFelingStaticValidation.test_provided_mmbt3904_model_card_is_detected_but_not_claimed_exact) ... ok
test_r96_r97_authoritative_designator (test_static.LIFelingStaticValidation.test_r96_r97_authoritative_designator) ... ok
test_ref3020_dbz_physical_pin_order (test_static.LIFelingStaticValidation.test_ref3020_dbz_physical_pin_order) ... ok
test_rv4_switch_mapping_is_physical (test_static.LIFelingStaticValidation.test_rv4_switch_mapping_is_physical) ... ok
test_schematic_crosscheck_has_no_missing_reference_or_footprint (test_static.LIFelingStaticValidation.test_schematic_crosscheck_has_no_missing_reference_or_footprint) ... ok
test_topology_corrections_have_no_blocking_failure (test_static.LIFelingStaticValidation.test_topology_corrections_have_no_blocking_failure) ... ok
test_tps610995_is_fixed_3v6_variant (test_static.LIFelingStaticValidation.test_tps610995_is_fixed_3v6_variant) ... ok
test_vendor_deck_requires_explicit_adapter_library (test_static.LIFelingStaticValidation.test_vendor_deck_requires_explicit_adapter_library) ... ok
test_vendor_profile_fails_until_ti_wrappers_are_approved (test_static.LIFelingStaticValidation.test_vendor_profile_fails_until_ti_wrappers_are_approved) ... ok
test_power_switch_off_uses_operating_point (test_suite_runtime.SuiteRuntimeRegression.test_power_switch_off_uses_operating_point) ... ok
test_run_deck_has_timeout_and_stale_cleanup (test_suite_runtime.SuiteRuntimeRegression.test_run_deck_has_timeout_and_stale_cleanup) ... ok

----------------------------------------------------------------------
Ran 30 tests in 0.309s

OK
```

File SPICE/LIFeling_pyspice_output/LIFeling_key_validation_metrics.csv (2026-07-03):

metric | value | run_label | notes
coverage_behavioural | 36 |  | component_model_coverage.csv
coverage_electrical | 165 |  | component_model_coverage.csv
coverage_mechanical | 6 |  | component_model_coverage.csv
coverage_terminal | 6 |  | component_model_coverage.csv
VREF_2V048_min | 2.048 | 02_baseline_self_spiking_coin | baseline
VREF_2V048_max | 2.048 | 02_baseline_self_spiking_coin | baseline
VREF_1V024_min | 1.02399 | 02_baseline_self_spiking_coin | baseline
VREF_1V024_max | 1.02399 | 02_baseline_self_spiking_coin | baseline
VDD_sag_max | 0.148833 | 02_baseline_self_spiking_coin | baseline
Battery_current_peak_mA_est | 2.97666 | 02_baseline_self_spiking_coin | baseline
Vm_Int_min | 0.463651 | 02_baseline_self_spiking_coin | baseline
Vm_Int_max | 0.883175 | 02_baseline_self_spiking_coin | baseline
Vm_Ext_max | 2.50194 | 02_baseline_self_spiking_coin | baseline
AP_rising_edges | 27 | 02_baseline_self_spiking_coin | baseline
Spike_Pulse_rising_edges | 27 | 02_baseline_self_spiking_coin | baseline
Peak_Window_rising_edges | 27 | 02_baseline_self_spiking_coin | baseline
Reset_Window_rising_edges | 27 | 02_baseline_self_spiking_coin | baseline
Spike_Out_rising_edges | 27 | 02_baseline_self_spiking_coin | baseline
AP_mean_period_ms | 53.8928 | 02_baseline_self_spiking_coin | baseline
synapse_midpoint_delta_vm_int_max_mV | 0.737407 | 06_synapse_midpoint_zero_effect_single | midpoint should be close to zero-effect
excitatory_delta_vm_int_max_mV | 118.328 | 07_synapse_excitatory_single_high | positive delta expected
inhibitory_period_delta_ms | 16.138 | 08_synapse_inhibitory_single_low | positive delta means slower firing
stimulus_positive_delta_vm_int_max_mV | -61.9546 | 09_external_stimulus_positive_subthreshold | positive delta expected
stimulus_negative_delta_vm_int_max_mV | -85.1172 | 10_external_stimulus_negative_subthreshold | negative delta expected

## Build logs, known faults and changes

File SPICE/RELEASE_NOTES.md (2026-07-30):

# Compatibility patch v4 — ngspice 46 parser fixes

- Replaced unsupported `mod()` in the portable TPS610995 oscillator with a standard parameterised `PULSE` sawtooth source.
- Preserved the official Microchip file unchanged and added `models/compatible/MCP6001_ngspice.lib`, translating only `R61 ... TC a b` to ngspice `TC=a,b`.
- Decks now include the compatibility copy.
- Explicit invalid ngspice paths now fail rather than silently falling back to another executable.
- Version reporting now extracts `ngspice-46` instead of the banner delimiter.
- Added three regression tests for these fixes.

# LIFeling SPICE reconstruction — release notes

Version: `2026.07.29-reconstruction-3`  
Authoritative netlist SHA-256: `d5a0bf3aa70e19a4470710342be6b2e11441efbc97374f23ff95af703fe9eeea`  
Stable source-lock SHA-256: `3d646856dcfc6cf83bdad7bc2d7c16ead7ec400a898091fd7690fa8e39884344`  
Full run-manifest SHA-256: `87eb637357a1027260e2ffd1ce82e50840871a28e3e1585e6bfe0e2e5fd3a9e3`

## Delivered state

- The electrical model is rebuilt from the attached KiCad netlist exported on 2026-07-29 at 20:56:15 by Eeschema 10.0.1.
- All 216 exported references and 112 nets are inventoried; there are no silent omissions or unresolved references in the hybrid profile.
- All package-pin and requested topology gates pass. The static test suite passes 20 tests with no failures or errors.
- 48 relocatable, deterministic ngspice decks are generated. Repeated generation with the same source lock produces identical deck filenames and SHA-256 hashes.
- ngspice was not installed in the execution environment, so the 48 transient decks are marked `not_executed`. No numerical or hardware-validation claim is made from them.

## Explicit warnings

1. The attached export uses `R96 = 100 kΩ` between `V_Stim_Drive` and `Vm_Int`; `R97` is absent.
2. `TPS610995DRVR` is the fixed 3.6 V variant. The old 3.3 V boost assumption is rejected.
3. REF3020 physical DBZ pins are verified, but the official TINA macro-model terminal declaration remains gated until its downloaded file is inspected and wrapped.

## Model policy

The default hybrid profile uses the provided official Microchip MCP6001/2/4 macro-model for U1-U3. Other devices use documented portable models until official packages are downloaded, terminal declarations are inspected and ngspice smoke tests pass. The strict vendor profile fails closed instead of guessing pin order or silently substituting a fallback.

## Run on Windows

```powershell
.\run_full_validation.ps1 -Profile hybrid -NgspiceBinary "C:\Spice64\bin\ngspice.exe"
```

Review `reports/validation_report.md`, `reports/connectivity_audit.md`, `reports/model_manifest.csv` and `reports/validation_verdict.md` after execution.

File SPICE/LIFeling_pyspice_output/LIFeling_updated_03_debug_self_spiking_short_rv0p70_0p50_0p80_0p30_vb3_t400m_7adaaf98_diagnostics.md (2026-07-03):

# LIFeling run diagnostics — 03_debug_self_spiking_short

Script version: `validation-suite-v4`
Analysis ignores first `20 ms`.

| Metric | Value |
|---|---:|
| `Vm_Int_min` | 0.463651 |
| `Vm_Int_max` | 0.883175 |
| `Vm_Int_end` | 0.882913 |
| `Vm_Ext_max` | 2.50194 |
| `V_Threshold_min` | 0.846917 |
| `V_Threshold_max` | 0.869245 |
| `Vm_threshold_crossings` | 7 |
| `Vm_first_threshold_crossing_ms` | 75.4917 |
| `AP_rising_edges` | 7 |
| `Spike_Pulse_rising_edges` | 7 |
| `Peak_Window_rising_edges` | 7 |
| `Reset_Window_rising_edges` | 6 |
| `Spike_Out_rising_edges` | 7 |
| `AP_mean_period_ms` | 53.711 |
| `Reset_Window_mean_period_ms` | 53.6774 |
| `V_Syn_State_min` | 1.00804 |
| `V_Syn_State_max` | 1.0183 |
| `/V_Syn_Drive_min` | 0.447784 |
| `/V_Syn_Drive_max` | 0.877124 |
| `VDD_min` | 2.85117 |
| `VDD_sag_max` | 0.148833 |
| `Battery_current_peak_mA_est` | 2.97666 |

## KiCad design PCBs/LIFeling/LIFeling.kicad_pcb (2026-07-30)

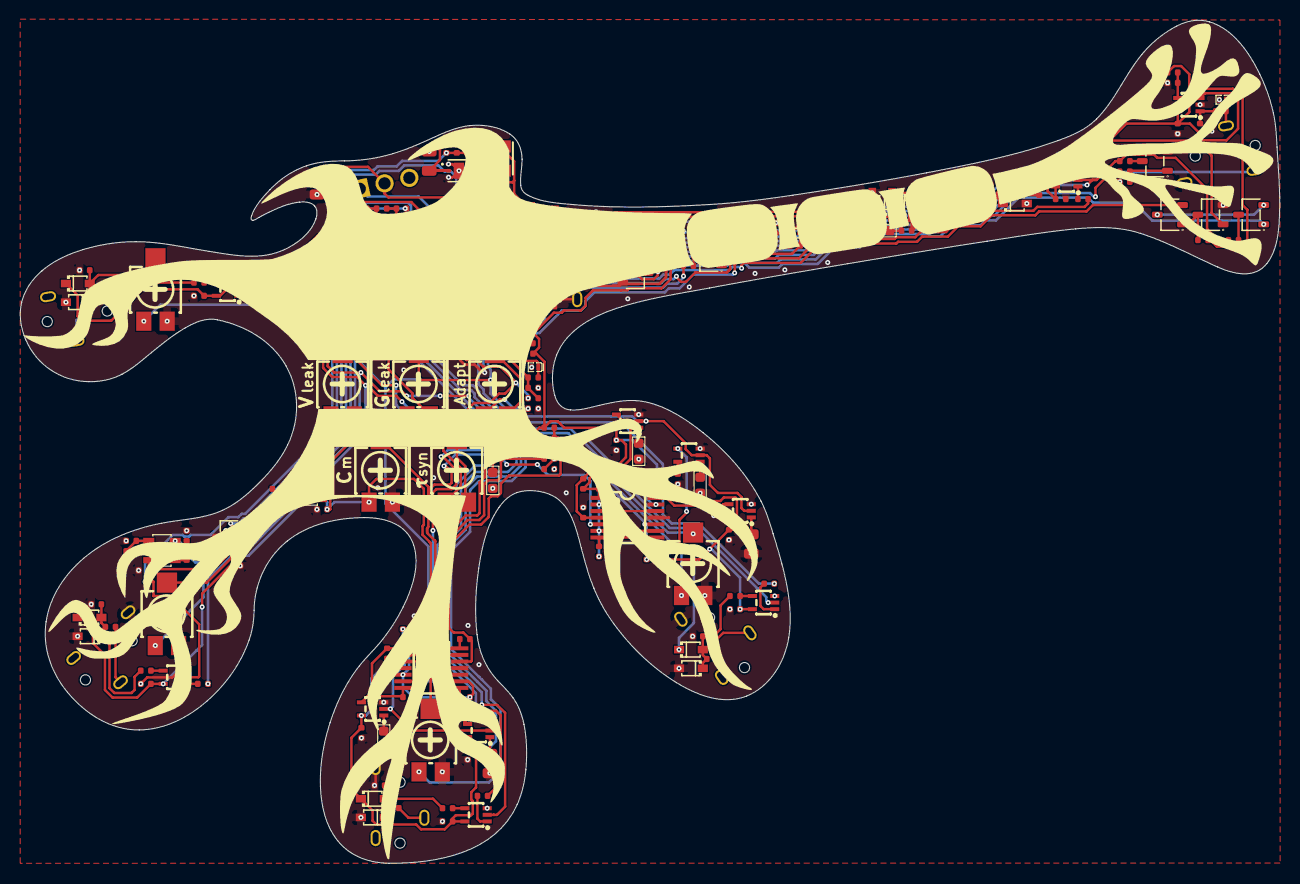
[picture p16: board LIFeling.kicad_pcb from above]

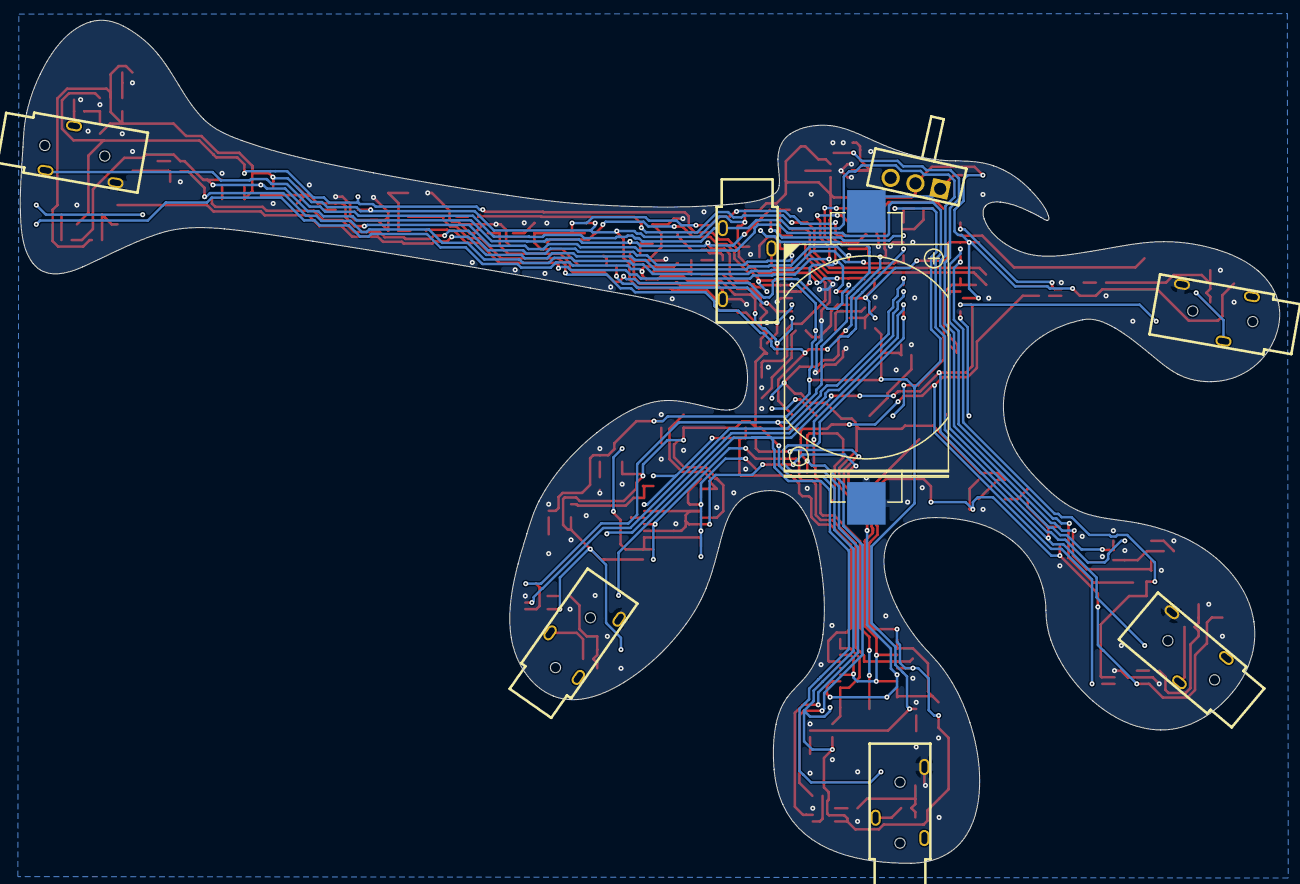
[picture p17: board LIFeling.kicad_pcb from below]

Board: 2 copper layers, 124.1 x 83.0 mm, 215 parts (8 on the bottom side), 106 nets.

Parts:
BT1: type="R" model="Battery_Cell" lib=""; BAT-TH_CR2032-BS-6-1
C1, C2, C9, C26, C30: 10uF; C_0805
C3, C4, C5, C6, C7, C8, C12, C14, C15, C17, C19, C21, C23, C25, C27, C32, C34, C35, C36, C37, C40, C41, C42: 100nF; C_0402
C10: 22uF; C_0805
C11, C33: 1uF; C_0402
C13, C28, C39: 100pF; C_0402
C16: 22nF; C_0402
C18: 470nF; C_0603
C20, C29: 1uF; C_0603
C22: 2.2uF; C_0603
C24: 4.7uF; C_0805
C31: 10nF; C_0402
C38: 220nF; C_0603
D1, D19: TPD1E05U06DPYT; X1SON-2_L1.0-W0.6-P0.65-RD-1
D2, D3, D10, D11, D12, D13, D14, D15, D16, D17, D21, D22: BAT54WS L9; SOD-323_L1.8-W1.3-LS2.5-RD
D4, D5, D7: 1N4148WS; SOD-323_L1.8-W1.3-LS2.5-RD-1
D6, D8, D20: RB521S30T1G; SOD-523_L1.2-W0.8-LS1.6-RD
D9: 19-237/R6GHBHC-A01/2T; LED-SMD_4P-L1.6-W1.6-19-237A-BHR6GHC-A01-2T
D18: TPD1E05U06DPYT; X1SON-2_L1.0-W0.6-P0.65-RD
H1, H2, H3, H4, H5, H6: MountingHole; MountingHole_2.2mm_M2
J1: Stim_Ext; AUDIO-SMD_HX-PJ-320A-3P-DIP
J2: Axon_Output; AUDIO-SMD_HX-PJ-320A-3P-DIP
J3: Syn1_Input; AUDIO-SMD_HX-PJ-320A-3P-DIP
J4: Syn2_Input; AUDIO-SMD_HX-PJ-320A-3P-DIP
J5: Syn3_Input; AUDIO-SMD_HX-PJ-320A-3P-DIP
J6: Syn4_Input; AUDIO-SMD_HX-PJ-320A-3P-DIP
L1: 2.2uH; IND-SMD_L3.0-W3.0_SMNR3015
Q1, Q3, Q4, Q5, Q6, Q7: BSS138; SOT-23-3_L2.9-W1.6-P1.90-LS2.8-BR
Q2, Q8: MMBT3904; SOT-23-3_L2.9-W1.6-P1.90-LS2.8-BR
R1: 10Ω; R_0402
R2: 220Ω; R_0402
R3, R16, R37, R46, R52, R60, R64, R82: 10kΩ; R_0402
R4, R8, R9, R11, R15, R17, R18, R19, R20, R21, R22, R24, R27, R30, R33, R38, R42, R43, R48, R49, R51, R55, R59, R65, R68, R72, R76, R80, R88, R92, R95, R96, R97: 100kΩ; R_0402
R5, R6, R13, R14, R58: 220kΩ; R_0402
R7: 20kΩ; R_0402
R10: 56kΩ; R_0402
R12, R23, R25, R26, R28, R29, R31, R32, R34, R50, R57, R83, R84, R85, R86, R90: 1MΩ; R_0402
R35, R67, R71, R75, R79, R91: 1kΩ; R_0402
R36: 2.2MΩ; R_0402
R39, R47, R53, R66, R69, R70, R73, R74, R77, R78, R81: 22kΩ; R_0402
R40, R54, R89: 100Ω; R_0402
R41, R44, R93, R94: 200kΩ; R_0402
R45: 330kΩ; R_0402
R56: 270kΩ; R_0402
R61, R62, R63: 2kΩ; R_0402
R87: 47kΩ; R_0402
RV1, RV3, RV4, RV5: 100kΩ; RES-ADJ-SMD_G43BT
RV2: 50kΩ; RES-ADJ-SMD_G43BT
RV6, RV7, RV8, RV9: 1MΩ; RES-ADJ-SMD_G43BT
SW1: K3-1260D-L1; SW-TH_K3-1260D-L1
U1, U2, U3: MCP6004T-I/ST; TSSOP-14_L5.0-W4.4-P0.65-LS6.4-BL
U4, U5, U6: TLV7044PWR; TSSOP-14_L5.0-W4.4-P0.65-LS6.4-BL
U7: TPS610995DRVR; WSON-6_L2.0-W2.0-P0.65-TL-EP
U8, U22: TLV9001IDBVR; SOT-23-5_L3.0-W1.7-P0.95-LS2.8-BR
U9, U10, U11, U12, U13, U14, U15, U16, U17, U18, U20: TS5A3166DCKR; SC-70-5_L2.1-W1.3-P0.65-LS2.1-BR
U19: TLV7031DCKR; SC-70-5_L2.1-W1.3-P0.65-LS2.2-BR
U21: REF3020AIDBZR; SOT-23-3_L3.0-W1.7-P0.95-LS2.9-BR

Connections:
+BATT: BT1.1 (+), C1.1, SW1.1
/AP_Gate: Q1.1 (G), R36.2, R37.2, U6.14 (OUTD)
/Adapt: R44.2, R45.1, U2.14 (VOUTD)
/Adapt_Base: Q2.1, R47.1, R48.1
/Adapt_Current_Sink: Q2.3, R46.2
/Adapt_Kick_Drive: C29.2, U2.1 (VOUTA), U2.2 (VINA-)
/Reset_Gated_Drive: Q6.3 (D), R60.1
/Reset_Injection_Drive: Q5.2 (S), U2.6 (VINB-), U2.7 (VOUTB)
/Reset_Injection_Enable: Q4.3 (D), Q5.1 (G), R59.2
/Reset_Switch_Mid: Q5.3 (D), Q6.2 (S)
/Reset_Timer_Discharge: Q3.3 (D), R54.1
/Rising_AP: C31.2, D8.2 (A), R49.1
/V_Leak_ref: RV1.2, U3.3 (VINA+)
/V_Syn_Drive: R86.2, R87.1, U1.14 (VOUTD)
/Vkick: C29.1, D4.1 (C), D5.2 (A), R39.2
AP: C31.1, Q1.3 (D), Q3.1 (G), R38.2, U2.3 (VINA+)
GNDREF: BT1.2 (-), C1.2, C2.2, C3.1, C4.1, C5.1, C6.1, C7.1, C8.1, C9.2, C10.1, C11.2, C12.2, C13.2, C14.2, C15.2, C16.1, C17.2, C18.2, C19.2, C20.2, C21.2, C22.2, C23.2, C24.2, C25.2, C26.2, C27.2, C28.1, C30.1, C32.2, C33.1, C34.2, C35.2, C36.2, C37.2, C38.1, C39.2, C40.2, C41.1, C42.1, D1.2 (GND), D3.2 (A), D4.2 (A), D7.2 (A), D11.2 (A), D13.2 (A), D15.2 (A), D17.2 (A), D18.2 (GND), D19.2 (GND), D20.2 (A), D22.2 (A), J1.3, J2.3, J3.3, J4.3, J5.3, J6.3, Q1.2 (S), Q2.2, Q3.2 (S), Q4.2 (S), Q7.2 (S), Q8.2, R4.1, R6.1, R8.2, R10.1, R12.1, R14.1, R21.2, R39.1, R40.2, R41.1, R48.2, R49.2, R50.1, R58.1, R65.2, R68.1, R72.1, R76.1, R80.1, RV1.1, RV4.1, RV6.1, RV7.1, RV8.1, RV9.1, U1.11 (VSS), U2.11 (VSS), U3.11 (VSS), U4.11 (VEE), U5.11 (VEE), U6.11 (VEE), U7.1 (GND), U7.3 (FB), U7.7 (PowerPad), U8.2 (V-), U9.3 (GND), U10.3 (GND), U11.3 (GND), U12.3 (GND), U13.3 (GND), U14.3 (GND), U15.3 (GND), U16.3 (GND), U17.3 (GND), U18.3 (GND), U19.2 (GND), U20.3 (GND), U21.3 (GND), U22.2 (V-)
unnamed: D6.2 (A), R45.2
unnamed: D9.3 (B-), R61.2
unnamed: D9.2 (G-), R62.2
unnamed: D9.1 (R-), R63.2
unnamed: D10.2 (A), D11.1 (K), R67.2, R68.2, R69.2
unnamed: D12.2 (A), D13.1 (K), R71.2, R72.2, R73.2
unnamed: D14.2 (A), D15.1 (K), R75.2, R76.2, R77.2
unnamed: D16.2 (A), D17.1 (K), R79.2, R80.2, R81.2
unnamed: Q7.3 (D), R61.1, R62.1
unnamed: Q8.1, R64.1, R65.1
unnamed: Q8.3, R63.1
unnamed: R35.1, RV2.1
unnamed: R40.1, RV3.3
unnamed: R82.2, RV5.1, RV5.2
unnamed: RV7.2, U1.5 (VINB+)
unnamed: R83.2, R84.2, U1.12 (VIND+)
unnamed: R85.2, R86.1, U1.13 (VIND-)
unnamed: RV6.2, U1.3 (VINA+)
unnamed: R41.2, R42.1, U2.12 (VIND+)
unnamed: R43.1, R44.1, U2.13 (VIND-)
unnamed: RV8.2, U3.10 (VINC+)
unnamed: RV9.2, U3.12 (VIND+)
unnamed: R92.2, R93.2, U6.5 (INB+)
unnamed: R94.2, R95.2, U6.6 (INB-)
unnamed: R56.1, R57.1, R58.2, U6.10 (INC+)
unnamed: C33.2, R53.2, R54.2, U6.9 (INC-)
unnamed: L1.2, U7.5 (SW)
unnamed: C10.2, R1.1, U7.2 (VOUT)
unnamed: C18.1, U9.1 (NO)
unnamed: C20.1, U10.1 (NO)
unnamed: C22.1, U11.1 (NO)
unnamed: C24.1, U12.1 (NO)
unnamed: C26.1, U13.1 (NO)
unnamed: R52.1, U14.1 (NO)
unnamed: R67.1, U15.4 (IN)
unnamed: R66.1, U15.1 (NO)
unnamed: R71.1, U16.4 (IN)
unnamed: R70.1, U16.1 (NO)
unnamed: R75.1, U17.4 (IN)
unnamed: R74.1, U17.1 (NO)
unnamed: R79.1, U18.4 (IN)
unnamed: R78.1, U18.1 (NO)
unnamed: R88.2, R89.1, U19.1 (OUT)
unnamed: R16.1, U20.1 (NO)
Peak_Window: Q4.1 (G), R51.2, U6.1 (OUTA), U14.4 (IN), U19.3 (IN+), U20.4 (IN)
Reset_Window: Q6.1 (G), Q7.1 (G), R55.2, R57.2, U6.8 (OUTC)
S0: R22.2, R23.2, U4.1 (OUTA), U9.4 (IN)
S1: R24.2, R25.2, R26.2, U4.7 (OUTB), U4.8 (OUTC), U10.4 (IN)
S2: R27.2, R28.2, R29.2, U5.1 (OUTA), U5.7 (OUTB), U11.4 (IN)
S3: R30.2, R31.2, R32.2, U5.8 (OUTC), U5.14 (OUTD), U12.4 (IN)
S4: R33.2, R34.2, U4.14 (OUTD), U13.4 (IN)
Spike_Out: D18.1 (I/O), J2.2, R89.2
Spike_Pulse: D8.1 (C), D20.1 (C), R50.2, U6.2 (INA+)
Stimulus_Ext: D19.1 (I/O), J1.2, R91.1
Syn1_Spike: J3.2, R69.1
Syn2_Spike: J4.2, R73.1
Syn3_Spike: J5.2, R77.1
Syn4_Spike: J6.2, R81.1
T1: R20.2, R21.1, R23.1, R25.1, U4.2 (INA+), U4.6 (INB-)
T2: R19.2, R20.1, R26.1, R28.1, U4.10 (INC+), U5.3 (INA-)
T3: R18.2, R19.1, R29.1, R31.1, U5.5 (INB+), U5.9 (INC-)
T4: R17.2, R18.1, R32.1, R34.1, U4.13 (IND−), U5.12 (IND+)
VDD: C2.1, C3.2, C4.2, C5.2, C6.2, C7.2, C8.2, C9.1, C17.1, C19.1, C21.1, C23.1, C25.1, C27.1, C32.1, C34.1, C35.1, C36.1, C37.1, C40.1, C41.2, C42.2, D2.1 (K), D9.4 (+), D10.1 (K), D12.1 (K), D14.1 (K), D16.1 (K), D21.1 (K), L1.1, R11.1, R13.2, R17.1, R22.1, R24.1, R27.1, R30.1, R33.1, R37.1, R38.1, R51.1, R53.1, R55.1, R56.2, R59.1, R88.1, R96.1, RV4.3, SW1.2, U1.4 (VDD), U2.4 (VDD), U3.4 (VDD), U4.4 (VCC), U5.4 (VCC), U6.4 (VCC), U7.4 (EN), U7.6 (VIN), U9.5 (V+), U10.5 (V+), U11.5 (V+), U12.5 (V+), U13.5 (V+), U14.5 (V+), U15.5 (V+), U16.5 (V+), U17.5 (V+), U18.5 (V+), U19.5 (VCC), U20.5 (V+), U21.1 (IN), U22.5 (V+)
VREF_1V024: R7.2, R9.1, R85.1, R90.1, R94.1, RV5.3, U22.1 (OUT), U22.4 (IN-)
VREF_1V024_RAW: R5.1, R6.2, U22.3 (IN+)
VREF_2V048: C15.1, R5.2, RV6.3, RV7.3, RV8.3, RV9.3, U3.5 (VINB+), U21.2 (OUT)
V_Boost: C11.1, C12.1, C14.1, R1.2, U8.5 (V+)
V_Leak: R43.2, RV2.3, U3.1 (VOUTA), U3.2 (VINA-)
V_Leak_Ref_Max: RV1.3, U3.6 (VINB-), U3.7 (VOUTB)
V_Logic_Mid: R13.1, R14.2, U19.4 (IN-)
V_Peak_Drive: R16.2, R52.2, U2.8 (VOUTC), U2.9 (VINC-)
V_Peak_Ref: R11.2, R12.2, U2.10 (VINC+)
V_Reset_Ref: R9.2, R10.2, U2.5 (VINB+)
V_Stim_Cmd: C39.1, R90.2, R91.2, R93.1
V_Stim_Drive: R95.1, R96.2, R97.1, U6.7 (OUTB)
V_Syn1_Set: U1.1 (VOUTA), U1.2 (VINA-), U15.2 (COM)
V_Syn2_Set: U1.6 (VINB-), U1.7 (VOUTB), U16.2 (COM)
V_Syn3_Set: U3.8 (VOUTC), U3.9 (VINC-), U17.2 (COM)
V_Syn4_Set: U3.13 (VIND-), U3.14 (VOUTD), U18.2 (COM)
V_Syn_State: C38.2, R66.2, R70.2, R74.2, R78.2, R82.1, R83.1
V_Threshold: R7.1, R8.1, R36.1, U6.3 (INA-), U6.12 (IND+)
Vm_Display_In: C16.2, D21.2 (A), D22.1 (K), R15.1, U8.3 (IN+), U20.2 (COM)
Vm_Ext: C13.1, D1.1 (I/O), J1.1, J2.1, R2.2
Vm_FB: R3.1, R4.2, U8.4 (IN-)
Vm_Int: C28.2, D2.2 (A), D3.1 (K), R15.2, R35.2, R42.2, R46.1, R60.2, R64.2, R84.1, R87.2, R92.1, R97.2, RV2.2, U6.13 (IND−), U9.2 (COM), U10.2 (COM), U11.2 (COM), U12.2 (COM), U13.2 (COM), U14.2 (COM)
Vm_Out_DRV: R2.1, R3.2, U8.1 (OUT)
Vsel: RV4.2, U4.3 (INA-), U4.5 (INB+), U4.9 (INC-), U4.12 (IND+), U5.2 (INA+), U5.6 (INB-), U5.10 (INC+), U5.13 (IND−)
Vw: C30.2, D5.1 (C), D6.1 (C), D7.1 (C), RV3.1, RV3.2, U1.10 (VINC+)
Vw_buff: R47.2, U1.8 (VOUTC), U1.9 (VINC-)

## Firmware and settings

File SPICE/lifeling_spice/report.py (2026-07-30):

"""Reader-facing validation report construction."""
from __future__ import annotations

import csv
import hashlib
import json
from pathlib import Path
from typing import Any

from .design import Design
from .audit import AuditFinding
from .models import FamilyResolution


def _read_json(path: Path, default: Any) -> Any:
    try:
        return json.loads(Path(path).read_text(encoding="utf-8"))
    except Exception:
        return default


def build_report(
    design: Design,
    source_manifest: list[dict[str, Any]],
    repository_snapshot: dict[str, Any],
    findings: list[AuditFinding],
    resolutions: list[FamilyResolution],
    execution_status: list[dict[str, Any]],
    output_path: Path,
    static_test_summary: dict[str, Any] | None = None,
) -> Path:
    output_path = Path(output_path)
    source_lock_path = output_path.parent / "source_lock.json"
    source_lock_sha = hashlib.sha256(source_lock_path.read_bytes()).hexdigest() if source_lock_path.is_file() else "not recorded"
    source_manifest_path = output_path.parent / "source_manifest.json"
    source_manifest_sha = hashlib.sha256(source_manifest_path.read_bytes()).hexdigest() if source_manifest_path.is_file() else "not recorded"
    attached_newer = repository_snapshot.get("attached_files_newer", True)
    schematic_crosscheck = _read_json(output_path.parent / "schematic_crosscheck.json", {})
    failures = [item for item in findings if not item.passed and item.severity == "error"]
    warnings = [item for item in findings if not item.passed and item.severity == "warning"]
    executed = [item for item in execution_status if item.get("status") == "passed"]
    failed_runs = [item for item in execution_status if item.get("status") == "failed"]
    not_run = [item for item in execution_status if item.get("status") == "not_executed"]
    static_test_summary = static_test_summary or {}
    static_count = int(static_test_summary.get("tests_run", 0) or 0)
    static_failures = int(static_test_summary.get("failures", 0) or 0)
    static_errors = int(static_test_summary.get("errors", 0) or 0)
    static_status = static_test_summary.get("status", "not recorded")

    lines = [
        "# LIFeling SPICE reconstruction and validation report",
        "",
        "## Executive conclusion",
        "",
        f"The electrical model was reconstructed from the attached KiCad export dated **{design.metadata.export_date}**, produced by **{design.metadata.tool}**. The export contains **{len(design.components)} components** and **{len(design.nets)} nets**. Connectivity in generated decks is derived from physical pins in that export; intended equations and previous behavioural mappings are not used as connectivity sources.",
        "",
        f"The static topology audit has **{len(failures)} blocking failures** and **{len(warnings)} explicit warnings**. " + ("No blocking topology failure remains." if not failures else "Blocking failures must be corrected before simulation results are accepted."),
        "",
        f"Transient execution status: **{len(executed)} passed**, **{len(failed_runs)} failed**, **{len(not_run)} not executed**. A non-executed run is not reported as electrical validation.",
        "",
        f"Static reconstruction tests: **{max(0, static_count - static_failures - static_errors)} passed, {static_failures} failures, {static_errors} errors** ({static_status}).",
        "",
        "> This system validates a SPICE representation. It does not constitute hardware validation, ESD qualification, battery-life certification, sustained-fault survival proof, PCB-parasitic validation, or production test evidence.",
        "",
        "## 1. Source and version lock",
        "",
        f"- Authoritative netlist SHA-256: `{design.metadata.sha256}`",
        f"- Stable source-lock SHA-256: `{source_lock_sha}`",
        f"- Full run-manifest SHA-256: `{source_manifest_sha}`",
        f"- KiCad source recorded in export: `{design.metadata.source}`",
        f"- Export date: `{design.metadata.export_date}`",
        f"- KiCad tool: `{design.metadata.tool}`",
        f"- Repository comparison commit: `{repository_snapshot.get('commit_sha','not recorded')}`",
        f"- Repository commit date: `{repository_snapshot.get('commit_date','not recorded')}`",
        f"- Attached files newer than repository comparison: **{'yes' if attached_newer else 'no'}**",
        "",
        "When attached and repository files differ, the attached netlist controls electrical connectivity. The schematic is a visual cross-check. The earlier Python implementation and historical outputs are comparison material only.",
        "",
        f"Schematic cross-check: **{schematic_crosscheck.get('placed_symbol_count','unknown')} placed symbols**, **{schematic_crosscheck.get('blocking_failures','unknown')} blocking mismatches**, **{schematic_crosscheck.get('warnings','unknown')} metadata warnings**. Escaped KiCad property strings are decoded before comparison, so the BT1 simulation-parameter value is compared exactly rather than truncated.",
        "",
        "### Source hashes",
        "",
        "| File | Type | Bytes | SHA-256 |",
        "|---|---|---:|---|",
    ]
    for row in source_manifest:
        lines.append(f"| `{row['file_name']}` | {row['source_type']} | {row['size_bytes']} | `{row['sha256']}` |")

    lines += [
        "",
        "## 2. Verified hardware corrections",
        "",
    ]
    for item in findings:
        if item.identifier.startswith(("pinmap.", "topology.rv4", "topology.peak_window", "topology.stimulus", "topology.u6b", "naming.stimulus", "power.boost")):
            result = "PASS" if item.passed else ("WARNING" if item.severity == "warning" else "FAIL")
            lines += [f"### {item.summary}", "", f"**{result}.** {item.evidence}", ""]
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

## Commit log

2025-08-28 create PCB
    [Spiky_Lui.kicad_pcb, Spiky_Lui.kicad_sch]
2025-08-28 update PCB
    [Spiky_Lui.kicad_pcb, Spiky_Lui.kicad_sch]
2026-05-09 PCB update
    [BOM.csv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]
2026-06-04 create SPICE
    [spiky_vm_passive_ideal.csv, spiky_vm_passive_ideal_vendor.csv]
2026-06-11 project restructure
    [BOM.csv, LIFeling.kicad_pcb, LIFeling.kicad_sch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]
2026-06-14 update Oscilloscope PCB
    [SpikyOscilloscopce-B_Adhesive.gbr, SpikyOscilloscopce-B_Courtyard.gbr, SpikyOscilloscopce-B_Cu.gbr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]
2026-06-14 update LIFeling PCB
    [LIFeling.kicad_sch]
2026-06-19 update PCB for oscilloscope
    [SpikyOscilloscopce.kicad_sch]
2026-06-19 update LIFelingPCB
    [LIFeling.kicad_sch]
2026-06-24 update pcb oscilloscope
    [SpikyOscilloscopce.kicad_sch]
2026-07-03 update SPICE version 5 - add_readme
    [LIFeling_key_validation_metrics.csv, LIFeling_updated_02_baseline_self_spiking_coin_rv0p70_0p50_0p80_0p30_vb3_t1p5_d99654c1_diagnostics.csv, LIFeling_updated_0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]
2026-07-30 updatre SPICE
    [BOM.csv, LIFeling.kicad_sch, N_01_full_operating.csv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]
